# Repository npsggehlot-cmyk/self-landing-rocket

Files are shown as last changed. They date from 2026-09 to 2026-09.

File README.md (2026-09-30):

# Self-Landing TVC Rocket

This is my build log and source repository for a 3-inch model rocket that steers itself with a thrust-vectored motor and is designed to land on its own legs. Everything is here: the custom flight computer (RocketFC), the 3D-printed avionics bay, the servo-driven parachute ejector, the flight software, and the simulators I use to test ideas before flying them.

**Current status:** Flight computer v2.1 is ordered from JLCPCB, fully assembled. The firmware is written and has been tested in simulation. The avionics bay and chute ejector are designed and ready to print. Next up is bench testing once the boards arrive, followed by a first flight using the parachute.

| Flight computer (top) | Avionics bay | 3D flight simulator |
|---|---|---|
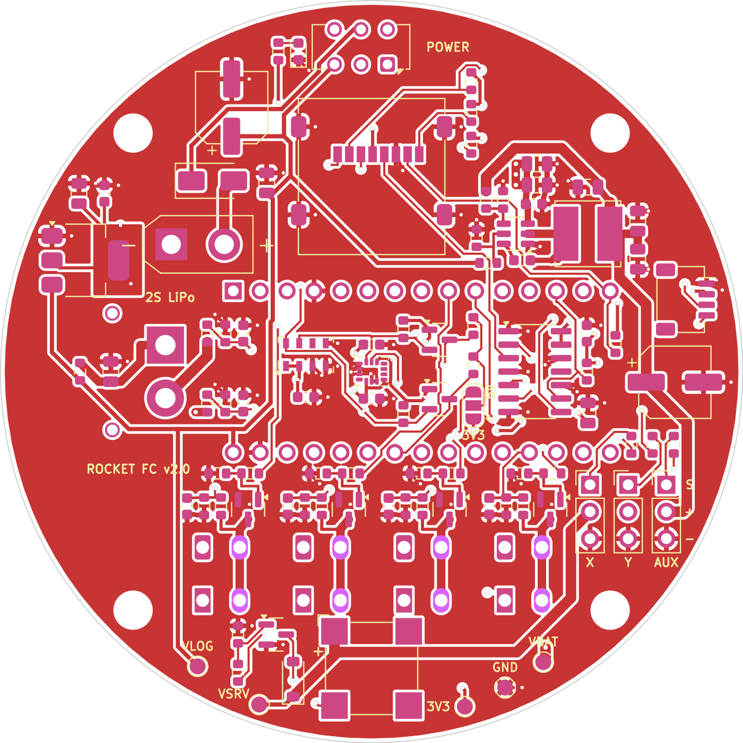
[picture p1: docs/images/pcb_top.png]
PCB top
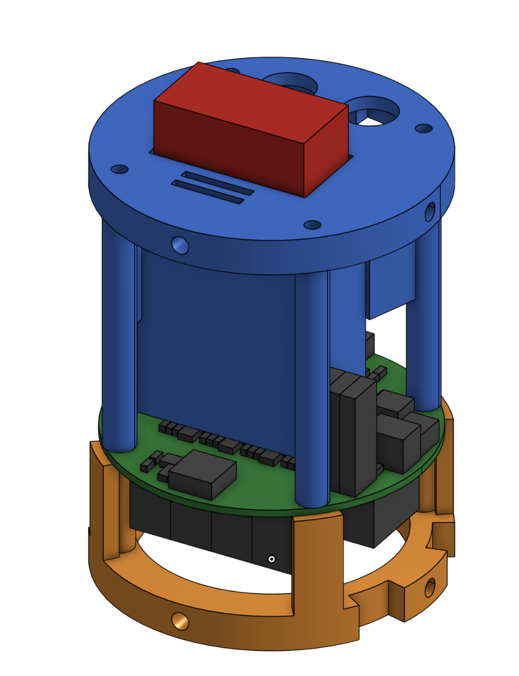
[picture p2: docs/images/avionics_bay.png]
Avionics bay
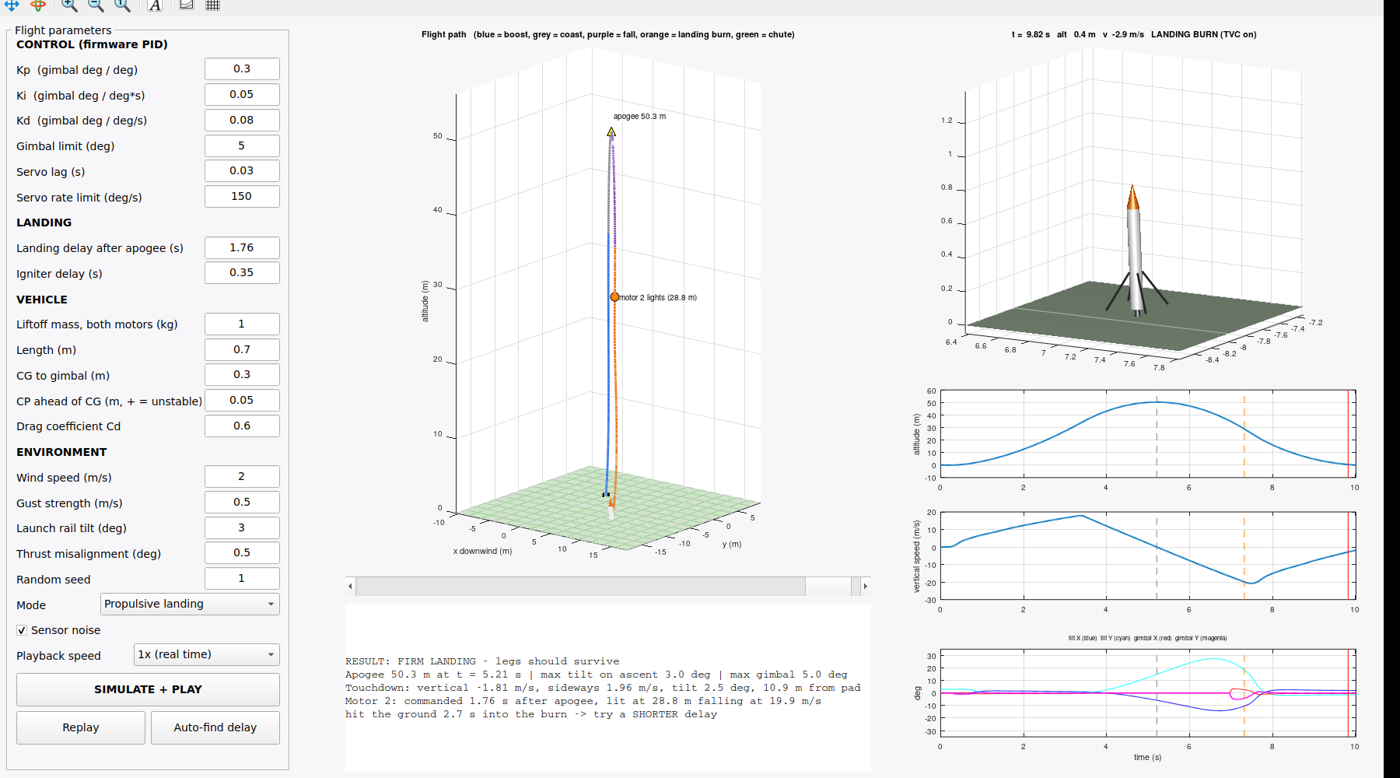
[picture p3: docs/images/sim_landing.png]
Simulator
|  |  |  |

---

## Mission profile

```mermaid
flowchart LR
    A[On the pad<br/>self-test beeps] -->|F15 #1 lit by<br/>launch controller| B[Boost<br/>TVC holds vertical]
    B -->|burnout at ~3.5 s| C[Coast]
    C -->|apogee| D{Flight mode}
    D -->|chute test| E[Servo releases the<br/>spring ejector and chute]
    D -->|landing| F[Free fall]
    F -->|timed so the burn<br/>ends at the ground| G[F15 #2 landing burn<br/>TVC on, legs released]
    E --> H[Legs released below 20 m]
    G --> I[Touchdown<br/>log closed, locator beeps]
    H --> I
```

## What's in this repo

| Folder | Contents | Start here |
|---|---|---|
| [`hardware/flight-computer`](hardware/flight-computer) | RocketFC v2.1, a 70 mm round 4-layer PCB designed in KiCad | `rocket_fc.kicad_pro`, plus Gerbers, BOM and CPL in `fabrication/` |
| [`hardware/avionics-bay`](hardware/avionics-bay) | Printed sled for the Apogee 3" tube, held in place by 8 radial M3 screws | STL and STEP files, tube drill template |
| [`hardware/chute-ejector`](hardware/chute-ejector) | Spring-loaded piston released by a servo-driven latch | Print-ready STLs |
| [`firmware/RocketFC`](firmware/RocketFC) | Arduino Nano flight software: TVC control, flight events, SD logging | `RocketFC.ino` |
| [`simulation/matlab`](simulation/matlab) | Interactive 3D flight simulator for tuning the PID gains and landing delay | `rocketSim3D.m` |
| [`simulation/firmware-sim`](simulation/firmware-sim) | Runs the actual flight firmware on a PC against simulated sensors | `sim.cpp` |
| [`LOG.md`](LOG.md) | Engineering log with a dated entry for each work session | |

## Flight computer overview

```
2S LiPo (XT30) ──┬── diode ── POWER switch ── Nano VIN + 3.3 V (sensors, SD card)
                 ├── 5 V 3 A buck, enabled by the switch ── 3 servos + buzzer
                 └── ARM plug (XT30) ── 4 low-side pyro channels (WAGO lever terminals)
```

| Function | Nano pin | Notes |
|---|---|---|
| Pyro P1 ascent, P2 landing, P3 legs, P4 spare | D2, D4, D6, D8 | AO3400A MOSFETs with 100k gate pull-downs; only live when the ARM plug is in |
| Continuity P1 to P4 | A0 to A3 | About 2.1 V when armed with an igniter connected, about 1.2 V when disarmed, 0 V when open |
| Servo X, servo Y (TVC), AUX (chute) | D3, D5, D7 | Powered from a separate 5 V buck converter |
| Battery and arm sense | A6, A7 | Battery voltage = A6 reading × 4.03 |
| IMU LSM6DSO32 (±32 g) and barometer MS5607 | I²C at 0x6A and 0x77 | Level-shifted to the 5 V Nano |
| microSD card (hinged lid) | SPI, D10 to D13 | Buffered through a 74LVC125 |
| Buzzer | D9 | Magnetic transducer, so it needs a tone rather than a steady signal |

Before ordering, the design passed a full design rule check with no errors, a pad-by-pad comparison between the schematic and the PCB (282 of 282 connections matched), an electrical rules check with no errors, and all 34 BOM lines were matched to parts in stock at JLCPCB.

## Key numbers

| | |
|---|---|
| Body tube | Apogee 3" (74.47 mm inner diameter); the bay and sled are 74.0 mm |
| Motors | 2 × Estes F15 (49.6 N·s total impulse, 25.3 N peak, 3.45 s burn) |
| Battery | 2S LiPo, 1000 mAh, 70 × 35 × 18 mm, XT30 connector |
| Simulated apogee at 1.0 kg | About 50 m |
| Best simulated landing delay | 1.76 s after apogee, with a window of roughly ±0.01 s |

## Links

- Onshape model of the avionics bay: [RocketFC Avionics Bay (3in Apogee tube)](https://cad.onshape.com/documents/a77bffe2781b56247ce74af7/w/bac2e3535b987d098c97ed26/e/773c68a36321aff5911a4cc4)

## Roadmap

- [x] Design, verify and order the flight computer PCB
- [x] Design the avionics bay and chute ejector
- [x] Write the firmware, compile it for the ATmega328P and test it in simulation
- [x] Build the 3D flight simulator in MATLAB
- [ ] Bench test the boards when they arrive: sensors, servos, and a pyro test with a small bulb
- [ ] Print the bay and ejector and test fit them in the tube
- [ ] Static test to measure the F15 igniter delay (`fire2` command)
- [ ] Flight 1: parachute mode with TVC on the way up
- [ ] Tune the PID gains using the flight logs
- [ ] Flight 2 and beyond: propulsive landing attempts

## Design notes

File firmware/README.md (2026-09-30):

# Firmware

`RocketFC/RocketFC.ino` builds in the Arduino IDE with the board set to "Arduino Nano" (ATmega328P). It only uses the built-in Wire, SPI, SD and Servo libraries.

Set `FLIGHT_MODE` near the top of the file, and fly the chute test first. For bench testing, open the Serial Monitor at 115200 baud with the line ending set to "Newline". The available commands are:

| Command | What it does |
|---|---|
| `s` | Prints status: sensors, battery, arm plug, continuity |
| `sweep` | Moves each TVC servo through its full range |
| `tvc` | Live TVC test, where the servos respond as you tilt the rocket |
| `open` / `lock` | Opens or locks the chute latch |
| `beep` | Tests the buzzer |
| `fire1` to `fire4` | Fires a pyro channel (only works with the ARM plug in) |

Each flight is logged to a new `FLTnn.CSV` file on the SD card.

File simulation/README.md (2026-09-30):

# Simulation

**`matlab/rocketSim3D.m`** runs in MATLAB, MATLAB Online or GNU Octave. Type `rocketSim3D`, adjust the PID gains, landing delay, mass or wind, and press SIMULATE + PLAY. The Auto-find button searches for the landing delay that gives the softest touchdown.

**`firmware-sim/`** compiles the real `RocketFC.ino` on a regular computer and runs it against simulated sensors:

```
g++ -O1 -w -Istub -o sim sim.cpp -lm
./sim 0    # 0 = chute flight, 1 = bump on the pad, 2 = landing
```

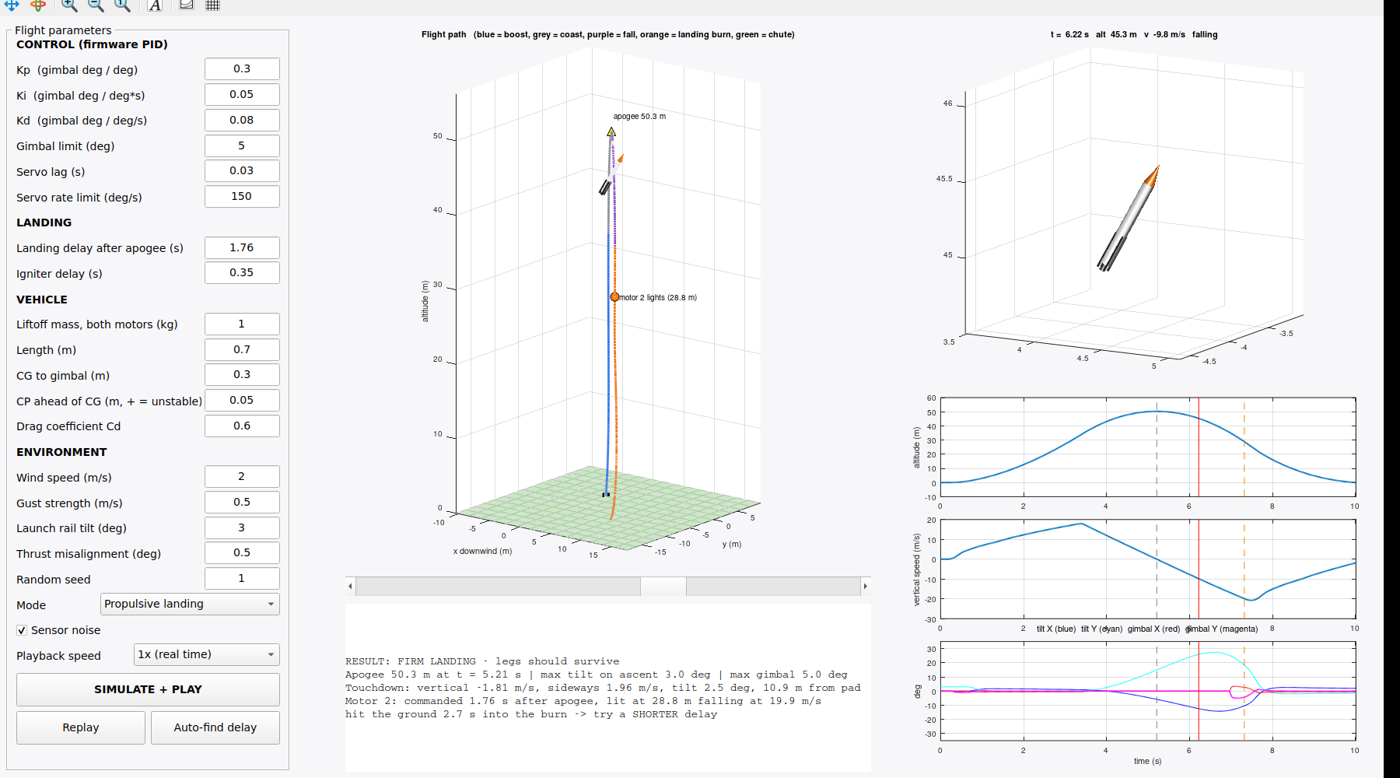
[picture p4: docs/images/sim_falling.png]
sim


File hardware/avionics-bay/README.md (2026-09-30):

# Avionics bay (Apogee 3" tube)

Print `AvBay_Aft.stl` and `AvBay_Forward.stl` in PETG. Joined by 4 × M3 × ~100 mm rods through the PCB holes (nut traps in the aft face).
8 × M3 heat-set inserts (4.0 mm hole) in radial bosses; drill the tube with `AvBay_Tube_Drill_Template.pdf` (print at 100 %).
Onshape: https://cad.onshape.com/documents/a77bffe2781b56247ce74af7/w/bac2e3535b987d098c97ed26/e/773c68a36321aff5911a4cc4
bay

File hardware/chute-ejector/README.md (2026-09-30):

# Servo parachute ejector

A compression spring (22 mm OD, 1.4–1.5 mm wire, 100 mm free, compressed to 35 mm) pushes a piston that throws out the chute.
A T-headed stem through the bulkhead is held by a latch cup on an MG90S servo horn; turning 90° lines up the slots and releases it.
The spring load goes into the cup and bulkhead, not the servo.

Print (PETG, no supports): `Print_Chute_Bulkhead.stl`, `Print_Chute_LatchCup.stl`, `Print_Chute_Stem.stl`, `Print_Chute_Piston.stl`.
Hardware: MG90S, 4 × M3 × 8 + heat-set inserts, M2 servo screws, Kevlar shock cord.
Arming: `open` → push the piston down until the T-head drops into the cup → `lock`.
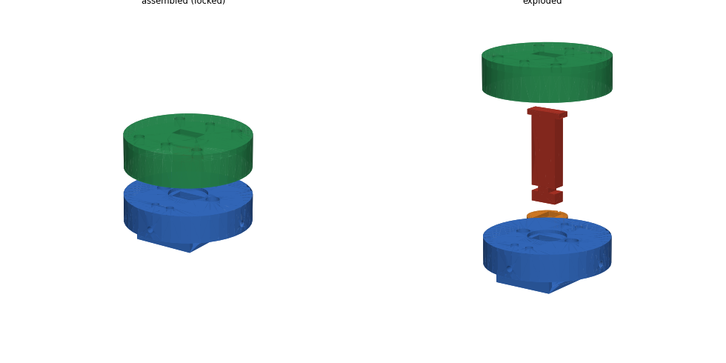
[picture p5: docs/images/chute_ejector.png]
ejector


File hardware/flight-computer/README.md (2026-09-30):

# RocketFC v2.1 flight computer PCB

Open `rocket_fc.kicad_pro` in KiCad 7 or newer.

- `fabrication/` holds exactly what was sent to JLCPCB: the Gerbers plus the full-assembly BOM and CPL files.
- `scripts/` has the Python scripts used to generate the schematic and board. `design.py` is the single source of truth for every part and net.
- `lib/` contains a local footprint for the WAGO 2601 lever terminals.

JLCPCB settings used: 4 layers, 1.6 mm, ENIG, Standard PCBA, assembly on both sides, parts placement confirmation, and depaneling.

When bringing up a new board, check the test pads first. VLOG should read about 7.9 V, VSRV 5.0 V and 3V3 3.3 V.

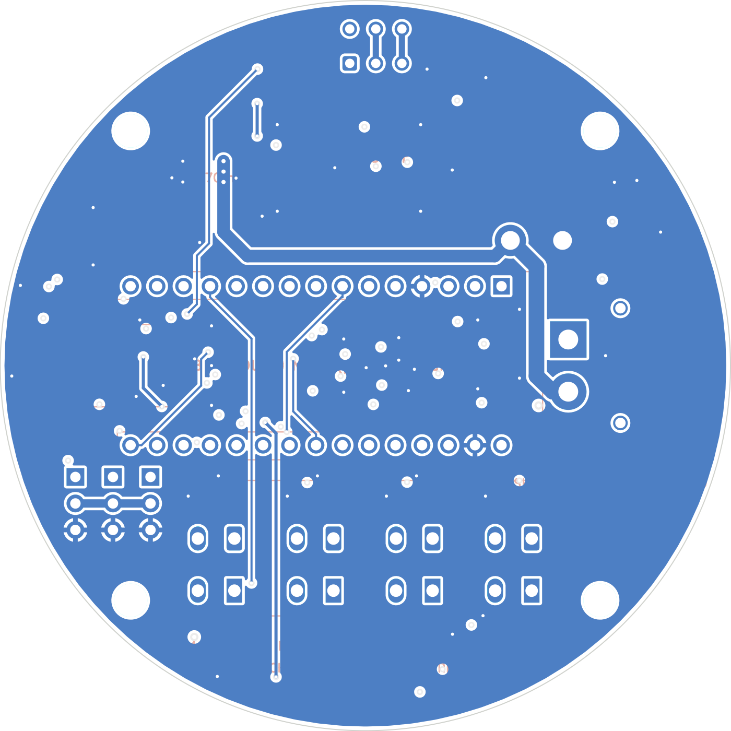
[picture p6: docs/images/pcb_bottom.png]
bottom
top

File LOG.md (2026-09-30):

# Engineering Log

Newest entries go at the top. Each entry covers one work session: what changed, why it changed, and what comes next. There's a blank template at the bottom of this file to copy for new entries.

---

## 2026-09-29: Firmware, 3D simulator and final PCB fixes

**Flight computer v2.1**
- A final review turned up one real problem. The I²C pull-up jumper (JP1) was shipping open, which would have required a solder bridge by hand. I tied it to the Nano's 5 V rail in copper, so the board now needs no hand soldering at all.
- Re-verified the Nano pin map against the KiCad library, compared the schematic to the PCB pad by pad (282 of 282 matched), and confirmed the design rule check and electrical rules check were both clean. Also double-checked the battery connector polarity (the chamfered side of an XT30 is negative) and the power switch wiring.
- Switched the JLCPCB order to full assembly: all surface-mount parts, the through-hole connectors and the Nano sockets, on both sides, with the edge rails removed. The Nano plugs into its sockets with the USB port facing the "< USB" arrow.

**Firmware (`firmware/RocketFC/RocketFC.ino`)**
- The flight states are PAD, BOOST, COAST, then either CHUTE or WAIT_IGNITE, then LAND_BURN and finally LANDED.
- TVC uses a gyro-integrated quaternion for attitude and a PID loop on tilt, with starting gains of Kp 0.30, Ki 0.05 and Kd 0.08 (degrees of gimbal per degree of tilt).
- Liftoff is detected at 1.5 g sustained for 50 ms, and the rocket must then climb 3 m within 2.5 s. If it doesn't, the computer goes back to the pad state, so bumping the rocket on the pad can't trigger the chute.
- An F15 can't be throttled, so the landing motor fires when a burn started at that moment would end right at the ground. If the apogee makes a soft landing impossible, the computer deploys the parachute instead.
- It fits on the Nano: 30,370 of 30,720 bytes of flash and 1,427 of 2,048 bytes of RAM.
- I ran the actual firmware against simulated sensors. The chute flight worked, a bump on the pad was correctly ignored, and the landing sequence worked.

**Chute ejector**
- A spring-loaded piston (22 mm OD spring, 100 mm free length) is held by a T-shaped stem that sits in a latch cup on an MG90S servo. Turning the servo 90° lines up the slots and releases it.

**3D simulator (`simulation/matlab/rocketSim3D.m`)**
- Lets me adjust the PID gains, the landing delay after apogee, the rocket's mass, CP/CG position, wind and more. An auto-find button searches for the softest landing.
- The best delay came out to about 1.76 s at 1.0 kg, and the usable window is only about ±0.01 s wide. The rocket also tilts 16 to 27° while coasting and falling, since there are no fins and the TVC is off, but the landing burn straightens it out in about 0.4 s.

**Next:** The boards should ship around October 8. Then comes bench testing.

---

## 2026-09-28: Flight computer v1 to v2, and the avionics bay

- Designed RocketFC in KiCad around an Arduino Nano and a 2S LiPo, with 4 pyro channels, 3 servo outputs, an IMU, a barometer and a microSD card.
- For v2, I shrank it to a 70 mm round board so it fits inside the Apogee 3" tube with room for the wall thickness, and moved the mounting holes to a standard 45 × 45 mm M3 pattern.
- Designed the avionics bay in Onshape and CadQuery. An aft ring and a forward bulkhead are joined by 4 M3 tie rods that pass through the PCB's mounting holes. 8 radial M3 heat-set inserts take screws through the tube wall, and there's a pocket for a 2S 1000 mAh battery.
- Fixed the geometry problems that caused Onshape import errors (curves, seam placement and thin walls).

---

## Template

```
## YYYY-MM-DD: Title

**What I did**
-

**What I learned or what went wrong**
-

**Data and photos** (images go in docs/images/, flight logs in data/)
-

**Next**
-
```

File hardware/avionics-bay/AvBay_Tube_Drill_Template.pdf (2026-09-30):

FORWARD (nose) end of the bay

RocketFC v2 avionics bay - tube drilling template (Apogee 3.0" / 74 mm body tube, OD 76.2 mm)

Print at 100 % (no "fit to page"), check the 50 mm bar, cut on the outline, wrap it around the tube printed side out, FORWARD edge toward the nose, left and right edges meeting. 8 small circles = 3.2 mm drill for M3 x 8 button-head screws into the heat-set inserts. Hatched boxes = openings to cut (USB, ARM plug, power switch).
Slide the bay in from the forward end with the power switch at 12 o'clock and line its screw holes up with the tube before drilling full size.

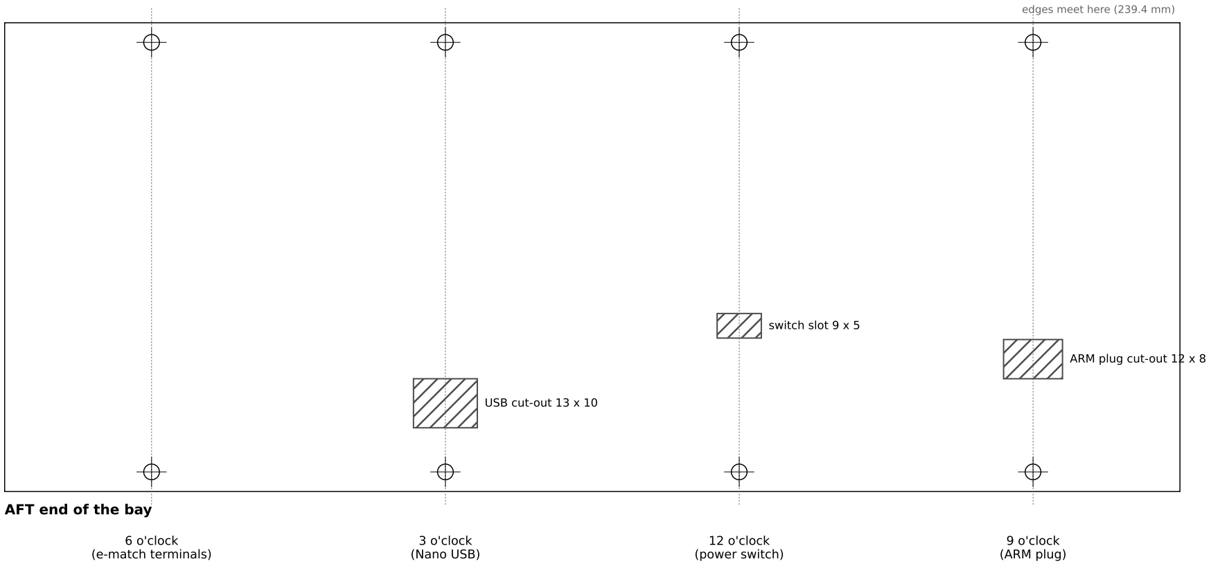
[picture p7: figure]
edges meet here (239.4 mm); 6 o'clock (e-match terminals); 3 o'clock (Nano USB); 12 o'clock (power switch); 9 o'clock (ARM plug); USB cut-out 13 x 10; ARM plug cut-out 12 x 8; switch slot 9 x 5; AFT end of the bay

50 mm check bar

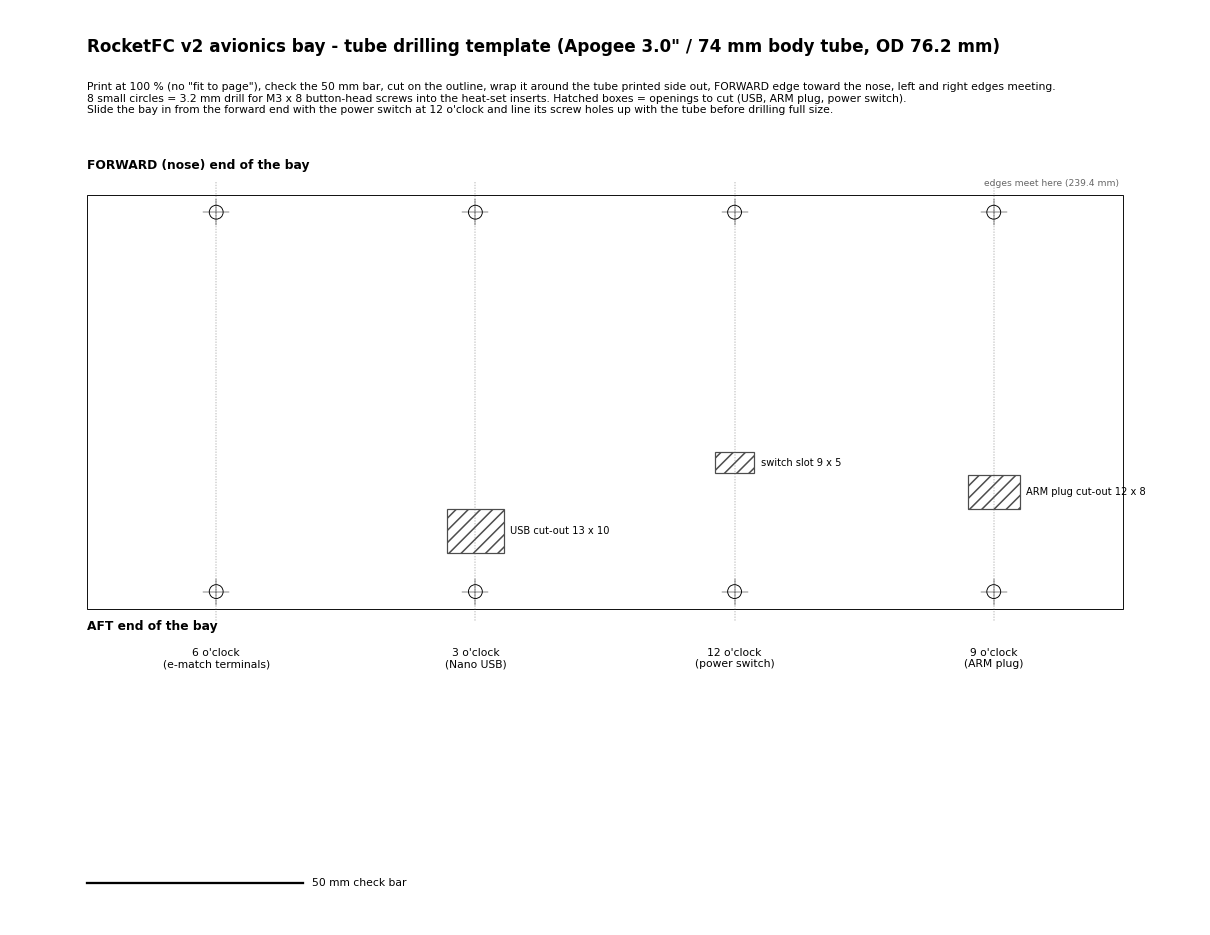
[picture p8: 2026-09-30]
docs/images/drill_template.png

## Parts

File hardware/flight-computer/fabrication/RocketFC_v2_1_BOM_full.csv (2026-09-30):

Comment | Designator | Footprint | LCSC Part #
CMT-8504 5V 100dB | BZ1 | MagneticBuzzer_CUI_CMT-8504-100-SMT | C22359707
220uF 16V | C1,C13 | CP_Elec_6.3x7.7 | C178534
10uF 25V | C2,C6,C7,C15,C24 | C_0805_2012Metric | C15850
10nF | C3,C14,C16,C17,C18,C19 | C_0603_1608Metric | C57112
22uF 25V | C4,C10,C11,C12 | C_0805_2012Metric | C45783
100nF | C5,C8,C9,C20,C21,C22,C23 | C_0603_1608Metric | C14663
SS34 | D1 | D_SMA | C8678
RED | D2 | LED_0603_1608Metric | C2286
1N4148W | D3 | D_SOD-123 | C81598
BATTERY 2S (XT30 male, vertical) | J1 | AMASS_XT30UPB-M_1x02_P5.0mm_Vertical | C428721
2.54mm 1x3 male header | J2,J3,J4 | PinHeader_1x03_P2.54mm_Vertical | C49257
ARM PLUG (XT30 female) | J5 | AMASS_XT30PW-F_1x02_P2.50mm_Horizontal | C2913282
WAGO 2601-3102 (lever) | J6,J7,J8,J9 | TerminalBlock_WAGO_2601-3102_1x02_P3.50mm_Vertical | C20252913
microSD (hinged lid) | J10 | microSD_HC_Molex_47219-2001 | C164170
QWIIC (GPS / rangefinder) | J11 | JST_SH_SM04B-SRSS-TB_1x04-1MP_P1.00mm_Horizontal | C160404
2.2uH | L1 | L_Bourns_SRN6045TA | C1332316
AO3400A | Q1,Q2,Q3,Q4,Q5 | SOT-23 | C20917
BSS138 | Q6,Q7 | SOT-23 | C40912
100k | R1,R4,R6,R7,R12,R15,R16,R19,R20,R23,R24,R27,R28,R31 | R_0603_1608Metric | C25803
33k | R2,R13,R17,R21,R25,R29 | R_0603_1608Metric | C4216
1k | R3 | R_0603_1608Metric | C21190
18k | R5 | R_0603_1608Metric | C25810
220 | R8,R9,R10 | R_0603_1608Metric | C22962
47k | R11 | R_0603_1608Metric | C25819
100 | R14,R18,R22,R26,R30 | R_0603_1608Metric | C22775
4.7k | R32,R33,R34,R35 | R_0603_1608Metric | C23162
10k | R36,R37,R38,R39,R40 | R_0603_1608Metric | C25804
POWER | SW1 | SW_CK_JS202011AQN_DPDT_Angled | C221662
AMS1117-3.3 | U1 | SOT-223-3_TabPin2 | C6186
TPS563200 | U2 | SOT-23-6 | C97253
LSM6DSO32 | U3 | LGA-14_3x2.5mm_P0.5mm_LayoutBorder3x4y | C1864162
MS5607-02BA03 | U4 | LGA-8_3x5mm_P1.25mm | C97627
74LVC125A | U5 | SOIC-14_3.9x8.7mm_P1.27mm | C7661
Nano socket 1x15 female 2.54mm | A1_S1,A1_S2 | PinSocket_1x15_P2.54mm_Vertical | C41417327

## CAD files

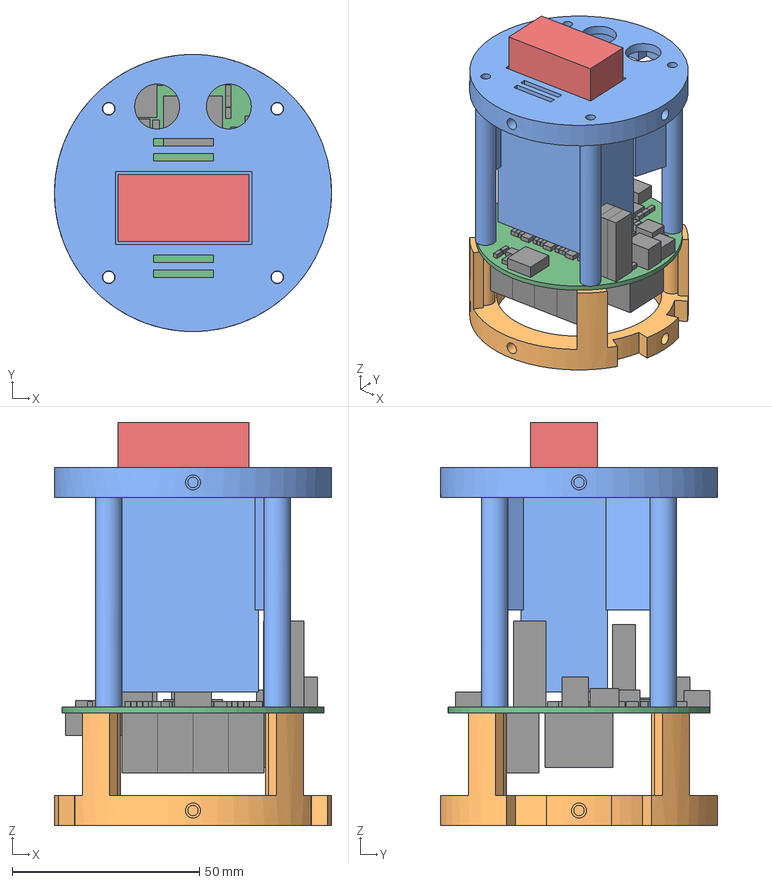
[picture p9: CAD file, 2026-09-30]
hardware/avionics-bay/AvBay_Assembly.step
74.0 x 74.0 x 107.6 mm
Sled_Aft
Sled_Forward
PCB_RocketFC_v2
PCB_component_envelopes
Battery_2S_1000mAh_70x35x18

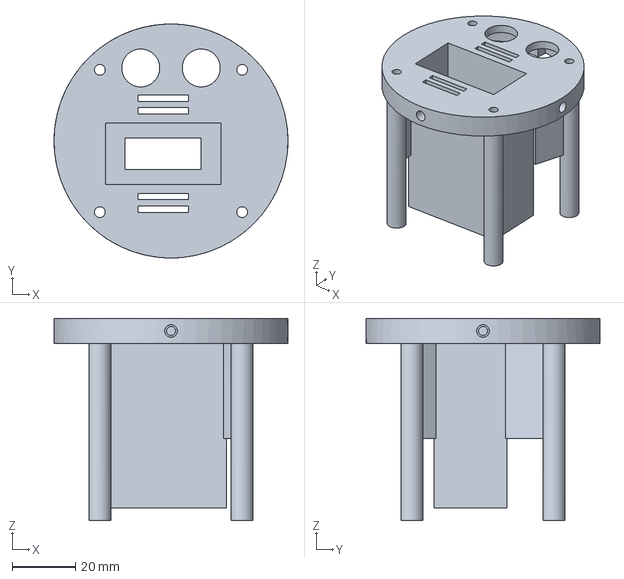
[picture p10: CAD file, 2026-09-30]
hardware/avionics-bay/AvBay_Forward.step
74.0 x 74.0 x 64.0 mm

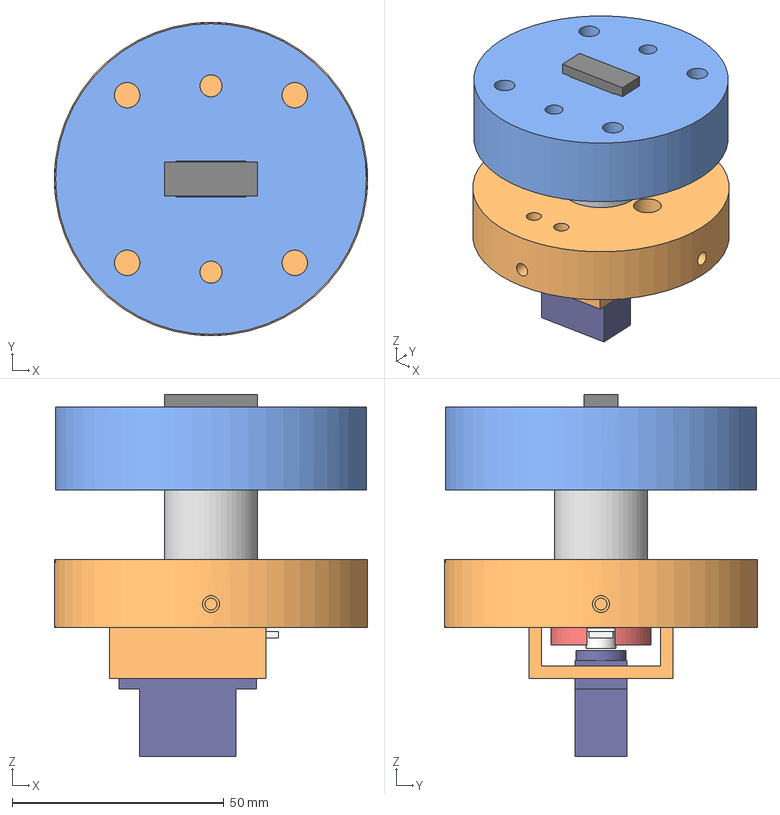
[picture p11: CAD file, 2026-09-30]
hardware/chute-ejector/RocketFC_Chute_Ejector.step
74.0 x 74.0 x 85.5 mm
Bulkhead_ServoFrame
Latch_Cup
Latch_Stem
Piston
REF_MG90S_servo
REF_servo_horn
REF_spring_20OD_x_100free

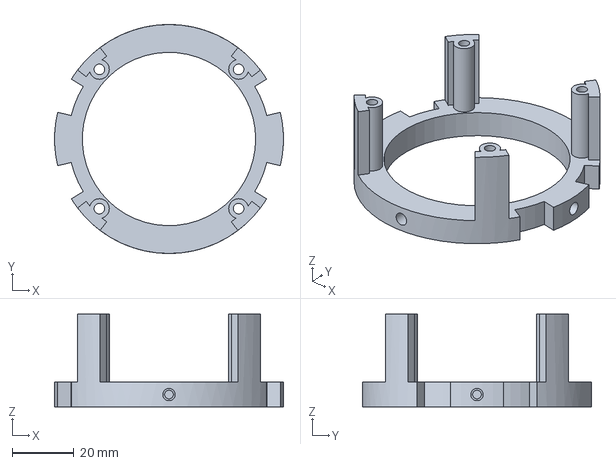
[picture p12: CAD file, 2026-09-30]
hardware/avionics-bay/AvBay_Aft.step
74.0 x 74.0 x 30.0 mm

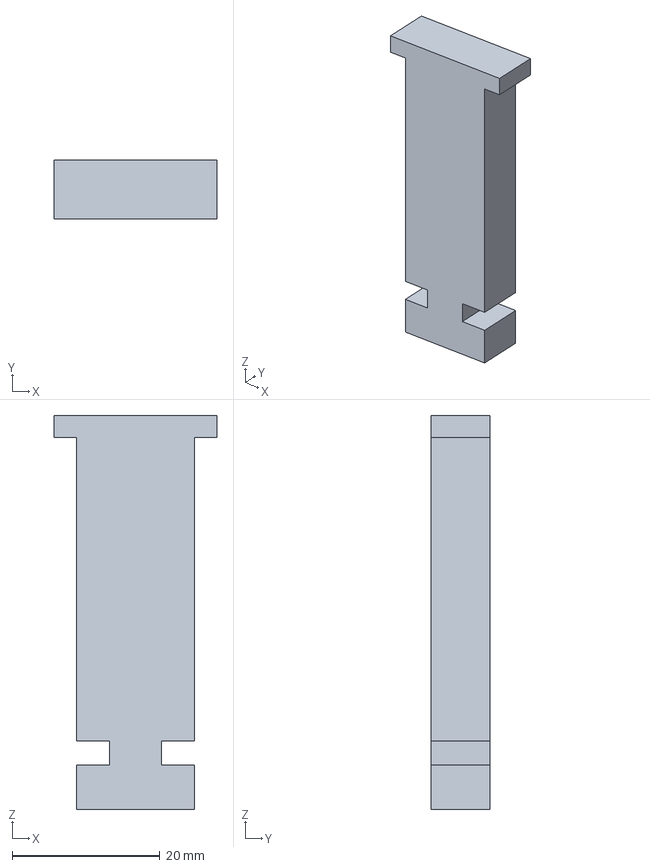
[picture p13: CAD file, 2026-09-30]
hardware/chute-ejector/ChuteEjector_stem.step
22.0 x 8.00 x 53.3 mm

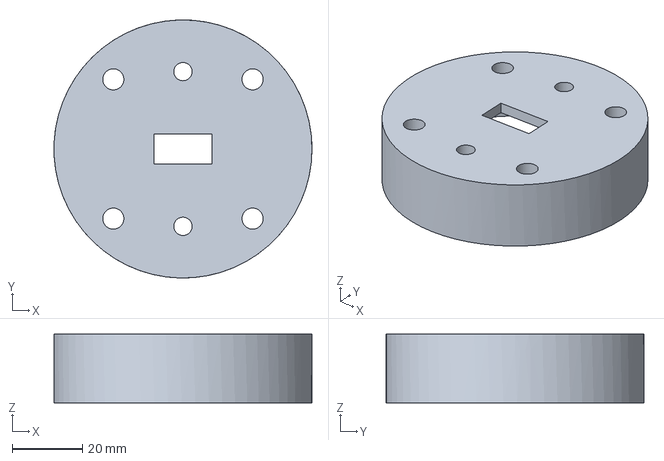
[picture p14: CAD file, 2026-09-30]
hardware/chute-ejector/ChuteEjector_piston.step
73.4 x 73.4 x 19.5 mm

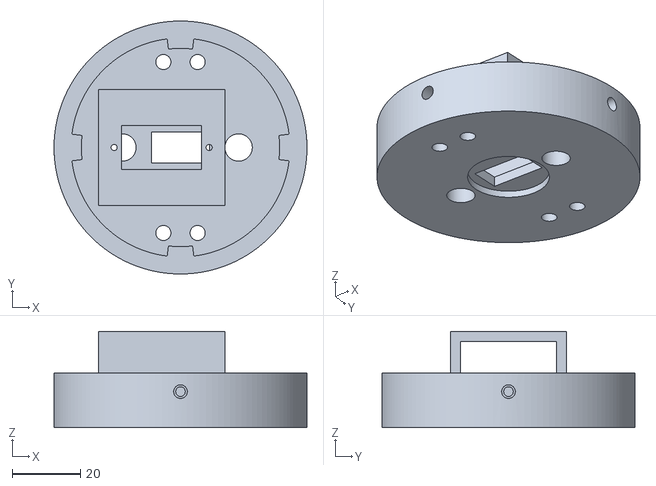
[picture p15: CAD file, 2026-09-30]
hardware/chute-ejector/Print_Chute_Bulkhead.stl
74.0 x 74.0 x 28.1

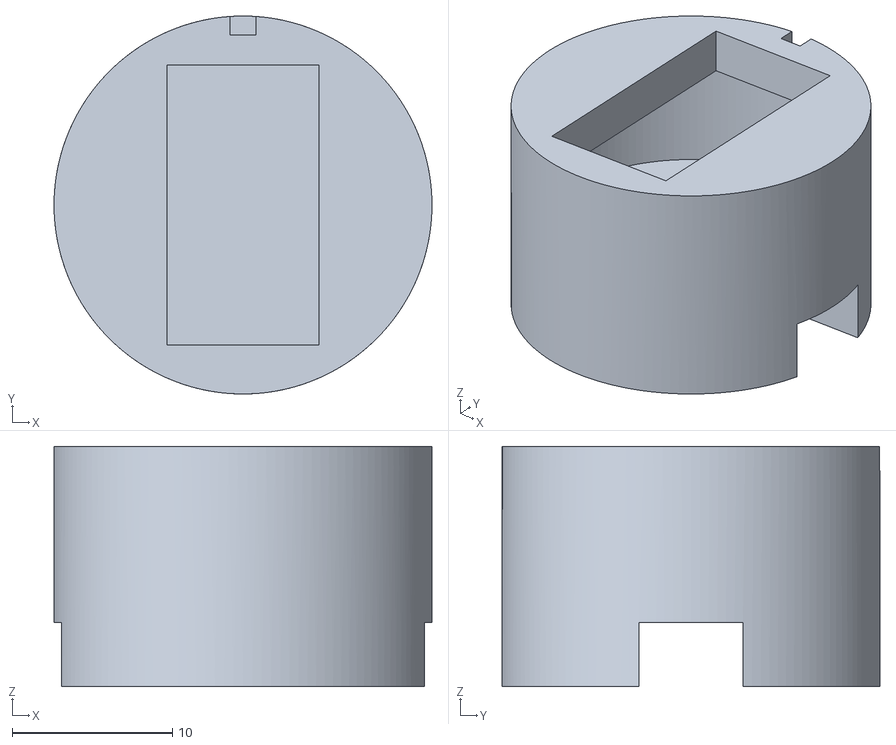
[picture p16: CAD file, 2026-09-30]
hardware/chute-ejector/Print_Chute_LatchCup.stl
23.6 x 23.6 x 15.0

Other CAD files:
hardware/chute-ejector/Print_Chute_Piston.stl
hardware/chute-ejector/ChuteEjector_bulkhead.step
hardware/chute-ejector/ChuteEjector_cup.step
hardware/chute-ejector/Print_Chute_Stem.stl
hardware/avionics-bay/AvBay_Aft.stl
hardware/avionics-bay/AvBay_Forward.stl

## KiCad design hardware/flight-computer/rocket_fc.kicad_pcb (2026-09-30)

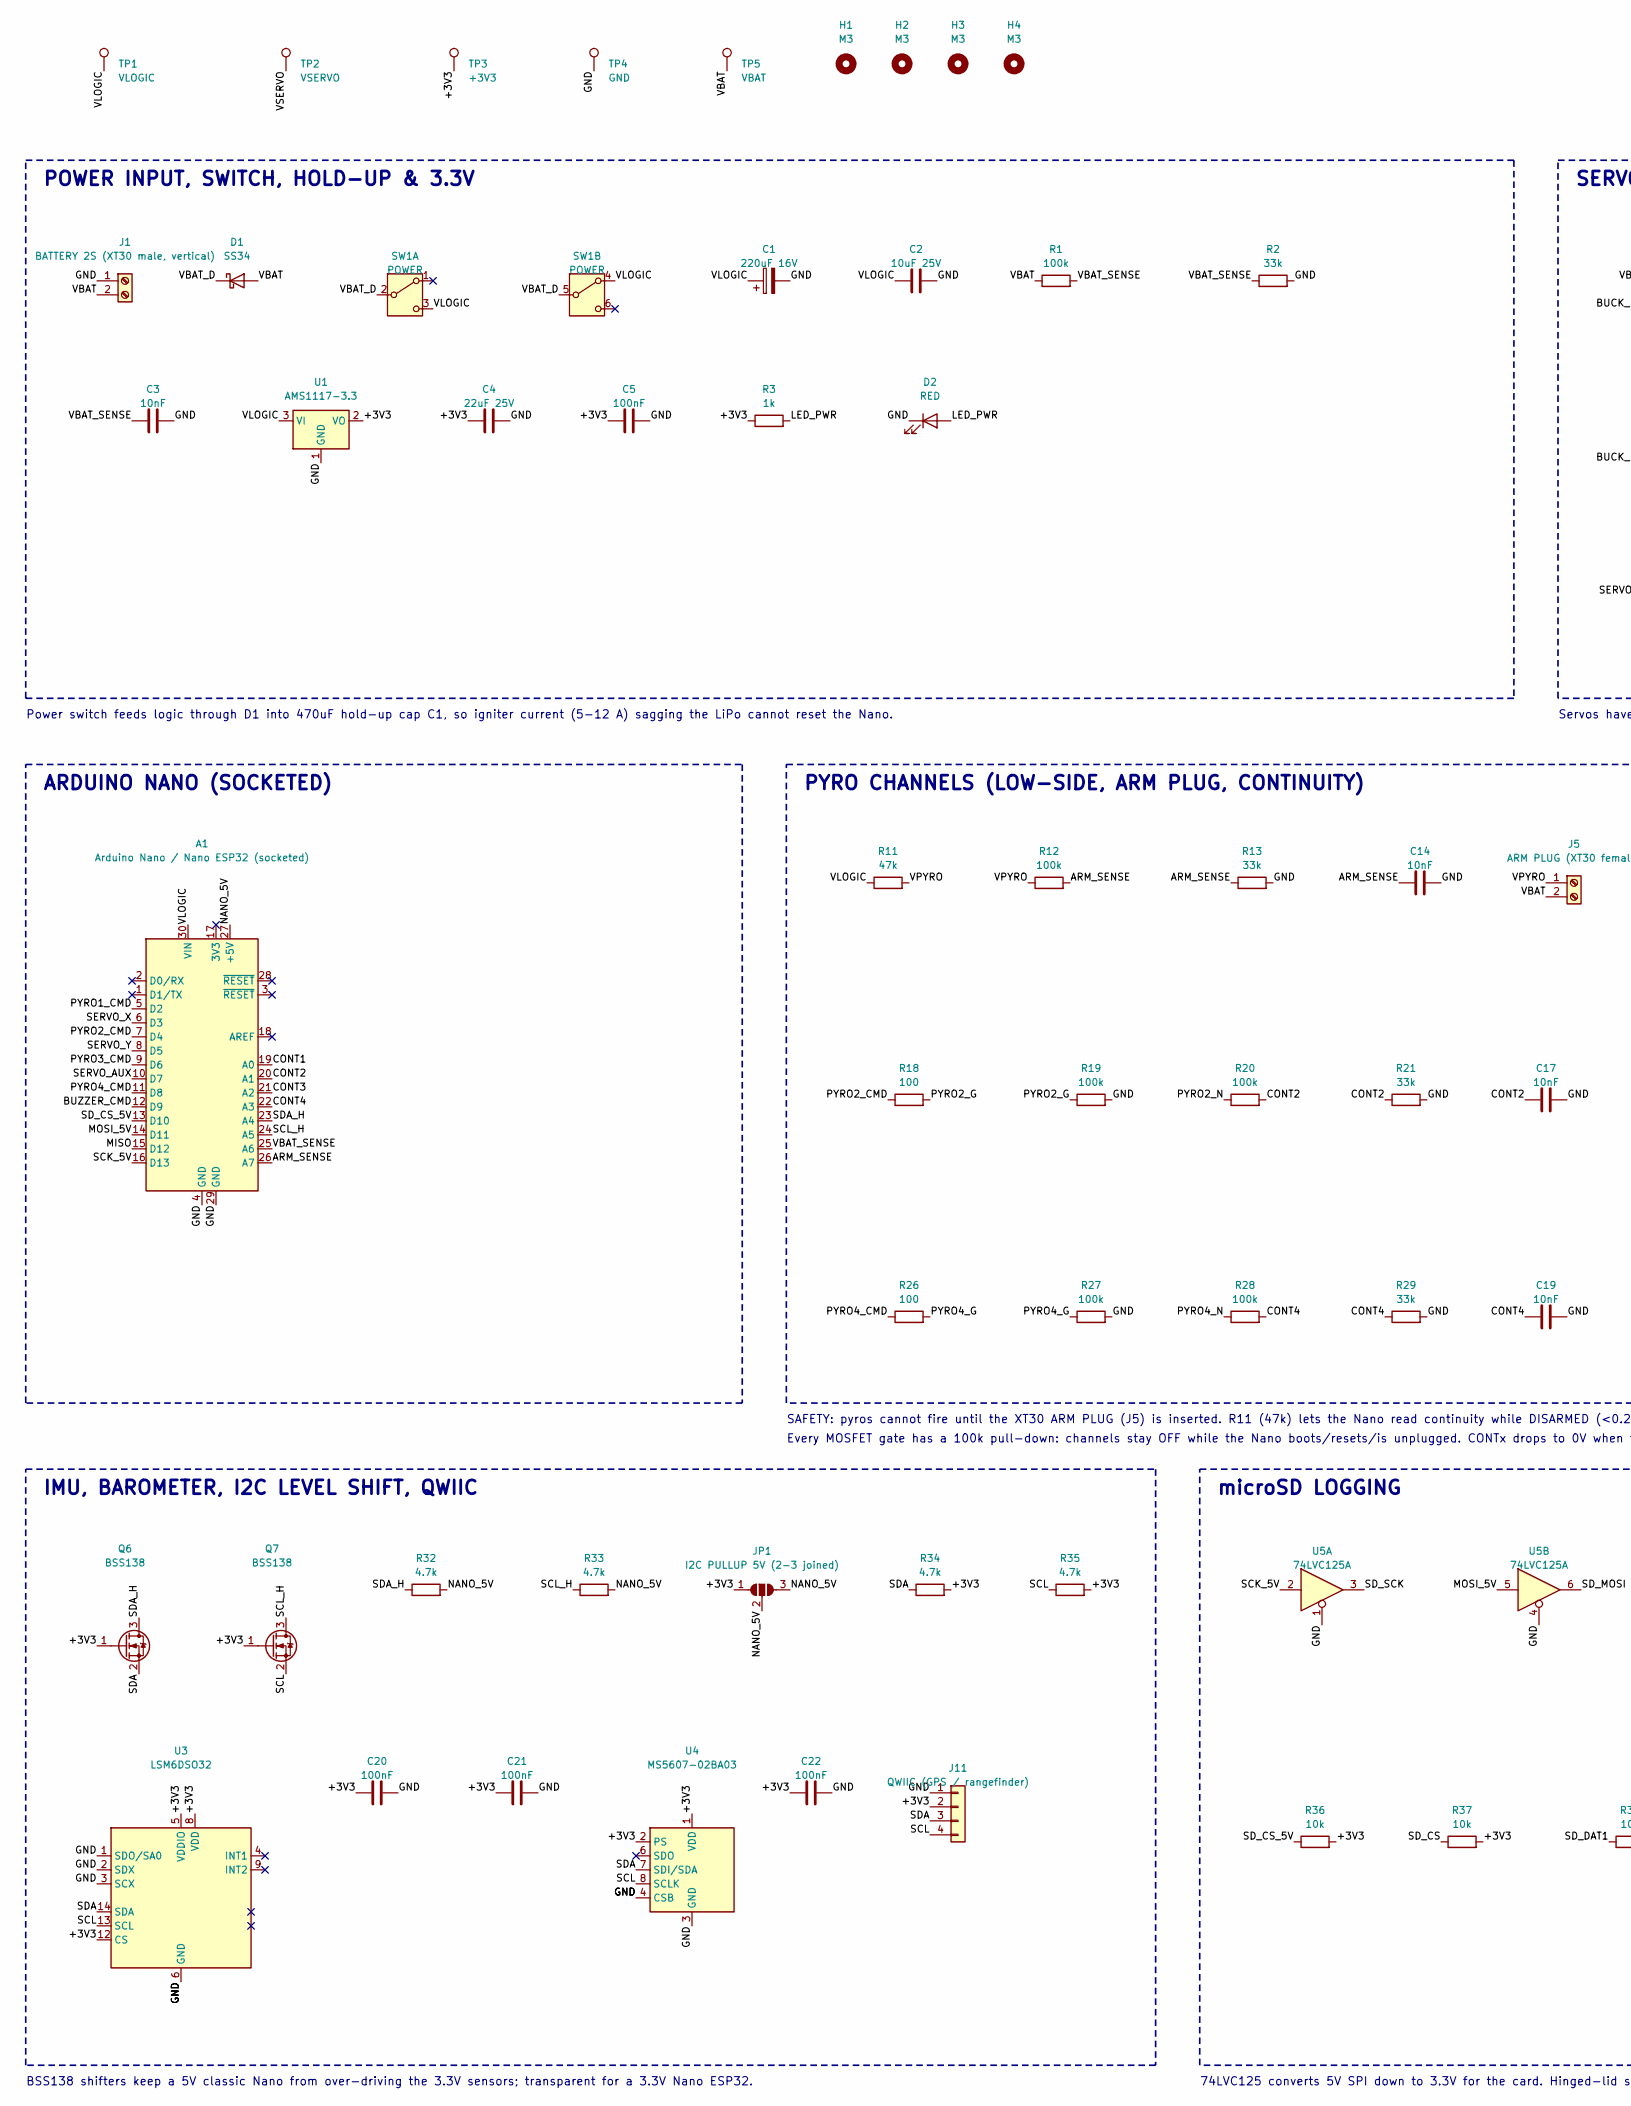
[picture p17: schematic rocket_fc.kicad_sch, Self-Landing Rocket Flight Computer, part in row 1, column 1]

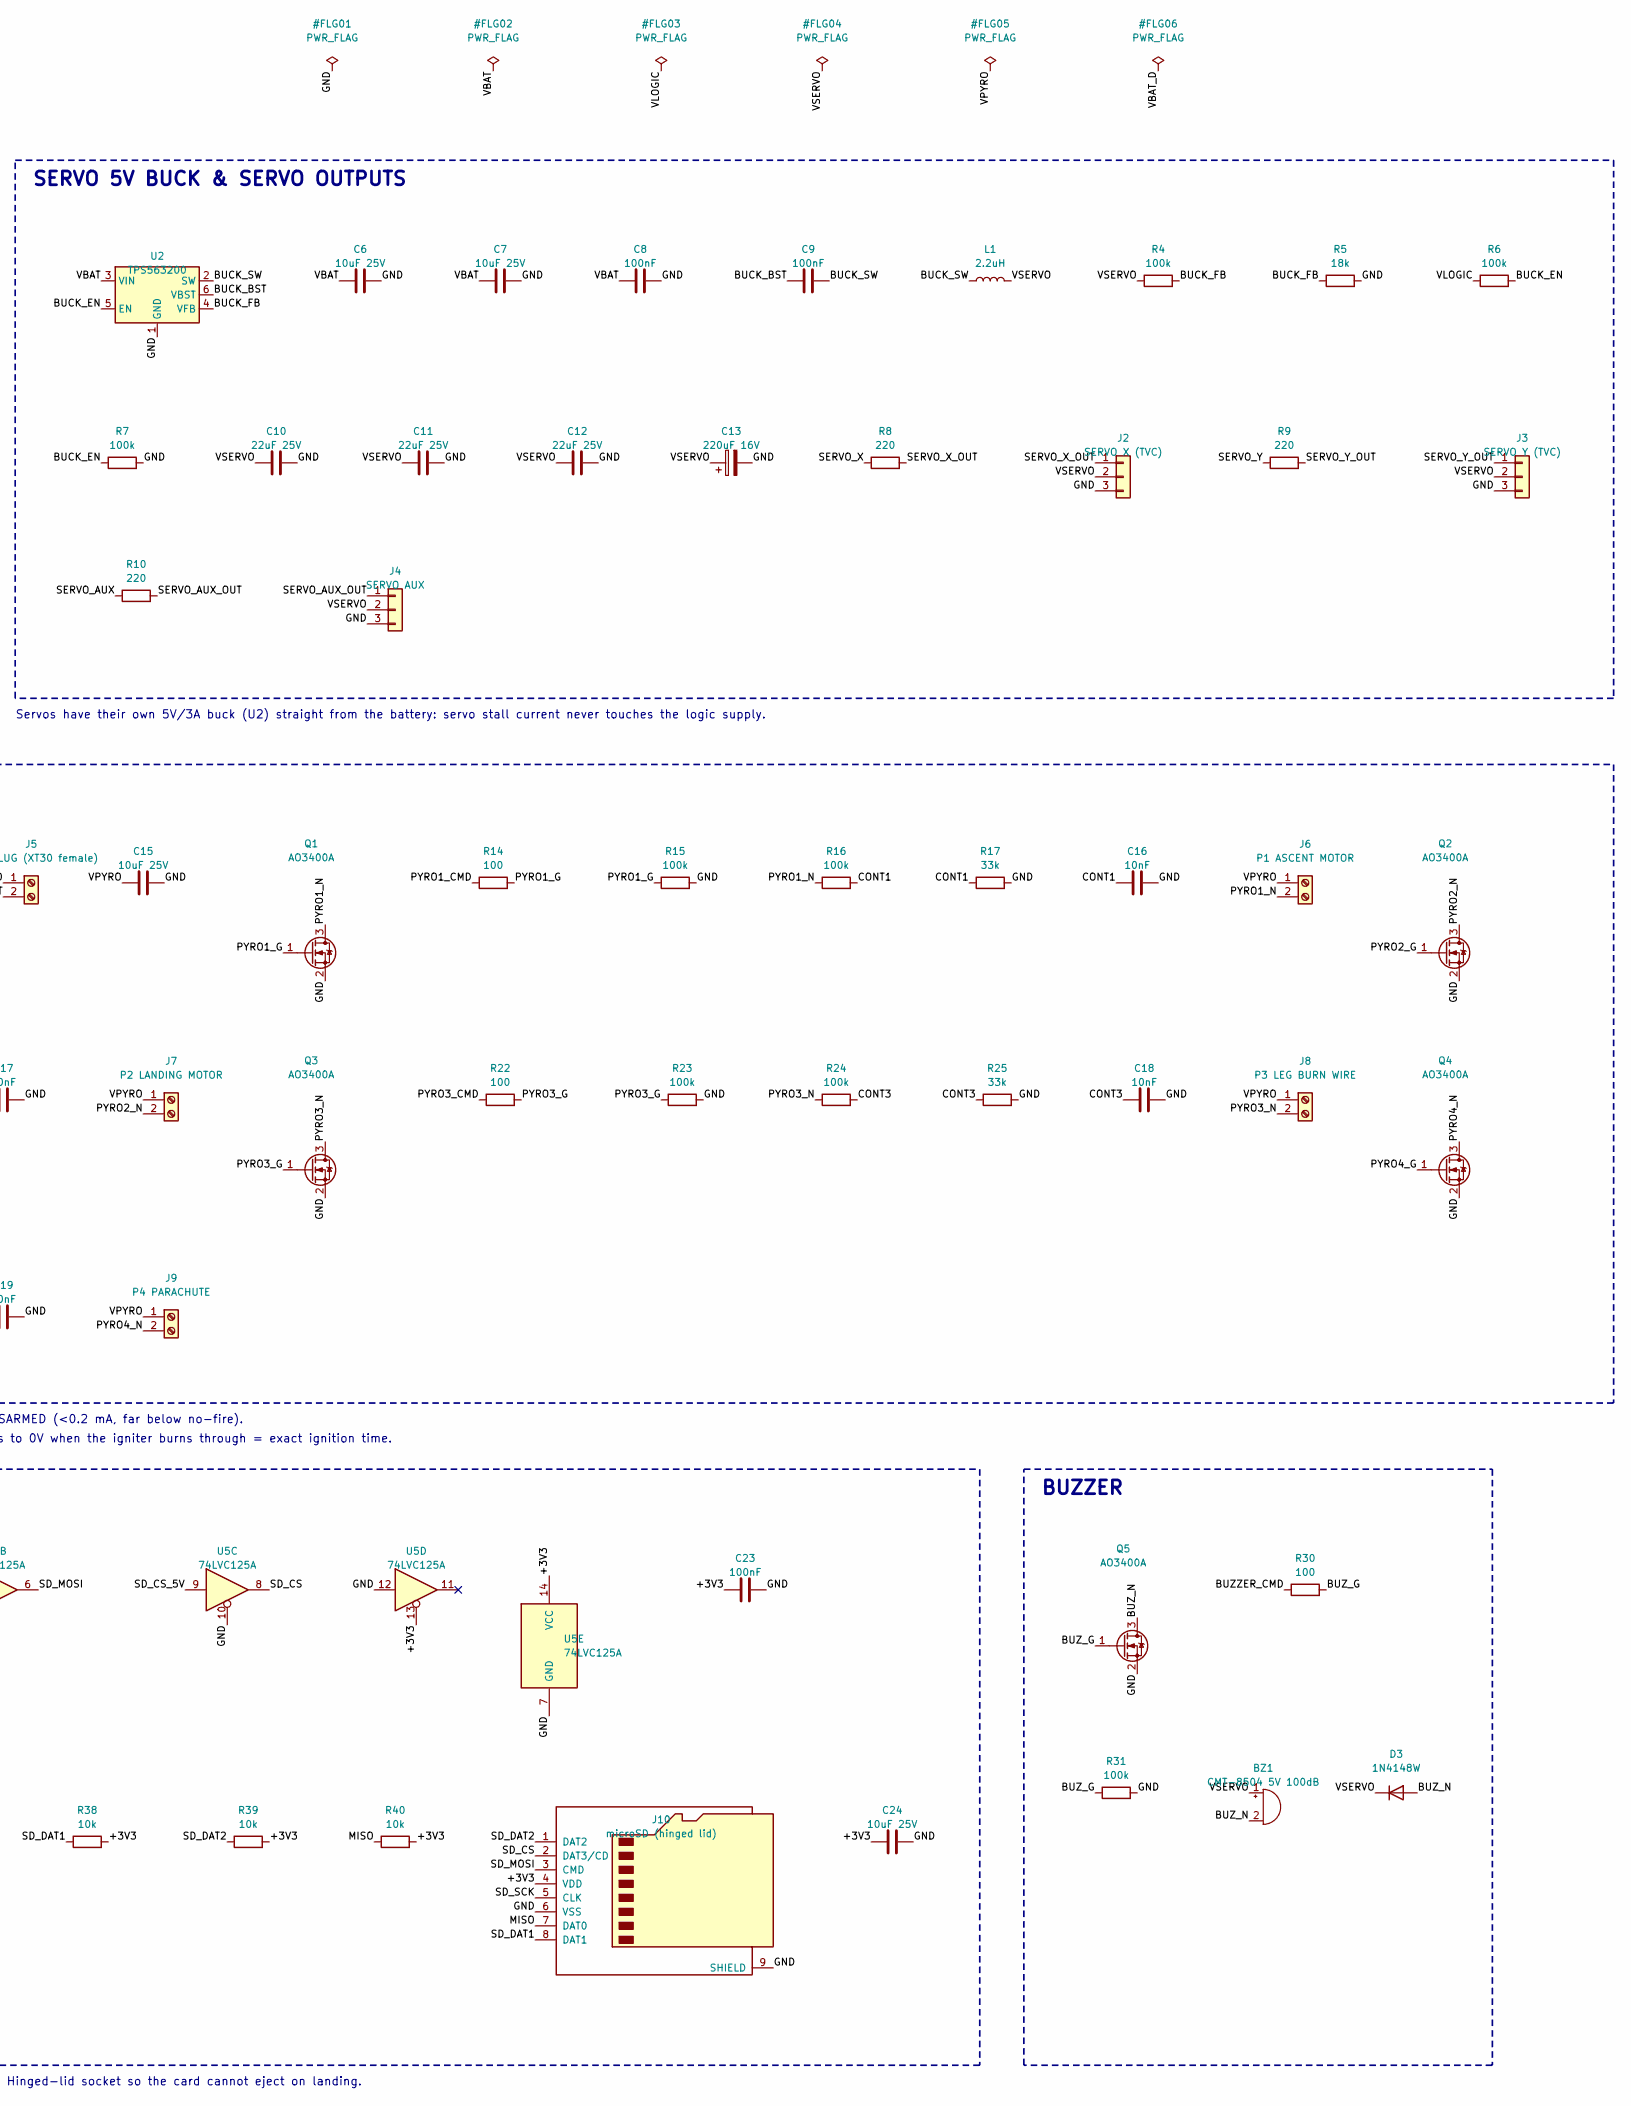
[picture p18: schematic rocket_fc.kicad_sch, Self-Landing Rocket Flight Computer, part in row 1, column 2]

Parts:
A1: Arduino Nano / Nano ESP32 (socketed); Arduino_Nano; MPN 2x 1x15 2.54mm female header (socket)
BZ1: CMT-8504 5V 100dB; MagneticBuzzer_CUI_CMT-8504-100-SMT; MPN Same Sky (CUI) CMT-8504-100-SMT-TR magn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; LCSC C22359707
C1: 220uF 16V; CP_Elec_6.3x7.7; MPN Panasonic EEE-FK1C221P 220uF 16V (brown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; LCSC C178534
C2, C6, C7, C15, C24: 10uF 25V; C_0805_2012Metric; LCSC C15850
C3, C14, C16, C17, C18, C19: 10nF; C_0603_1608Metric; LCSC C57112
C4, C10, C11, C12: 22uF 25V; C_0805_2012Metric; LCSC C45783
C5, C8, C9, C20, C21, C22, C23: 100nF; C_0603_1608Metric; LCSC C14663
C13: 220uF 16V; CP_Elec_6.3x7.7; MPN Panasonic EEE-FK1C221P 220uF 16V (servo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; LCSC C178534
D1: SS34; D_SMA; MPN SS34 (40V 3A Schottky); LCSC C8678
D2: RED; LED_0603_1608Metric; MPN KT-0603R red LED; LCSC C2286
D3: 1N4148W; D_SOD-123; MPN 1N4148W; LCSC C81598
H1, H2, H3, H4: M3; MountingHole_3.2mm_M3
J1: BATTERY 2S (XT30 male, vertical); AMASS_XT30UPB-M_1x02_P5.0mm_Vertical; MPN AMASS XT30UPB-M; LCSC C428721
J2: SERVO X (TVC); PinHeader_1x03_P2.54mm_Vertical; MPN 2.54mm 1x3 male header; LCSC C49257
J3: SERVO Y (TVC); PinHeader_1x03_P2.54mm_Vertical; MPN 2.54mm 1x3 male header; LCSC C49257
J4: SERVO AUX; PinHeader_1x03_P2.54mm_Vertical; MPN 2.54mm 1x3 male header; LCSC C49257
J5: ARM PLUG (XT30 female); AMASS_XT30PW-F_1x02_P2.50mm_Horizontal; MPN AMASS XT30PW-F; LCSC C2913282
J6: P1 ASCENT MOTOR; TerminalBlock_WAGO_2601-3102_1x02_P3.50mm_Vertical; MPN WAGO 2601-3102 (lever); LCSC C20252913
J7: P2 LANDING MOTOR; TerminalBlock_WAGO_2601-3102_1x02_P3.50mm_Vertical; MPN WAGO 2601-3102 (lever); LCSC C20252913
J8: P3 LEG BURN WIRE; TerminalBlock_WAGO_2601-3102_1x02_P3.50mm_Vertical; MPN WAGO 2601-3102 (lever); LCSC C20252913
J9: P4 PARACHUTE; TerminalBlock_WAGO_2601-3102_1x02_P3.50mm_Vertical; MPN WAGO 2601-3102 (lever); LCSC C20252913
J10: microSD (hinged lid); microSD_HC_Molex_47219-2001; MPN Molex 47219-2001 (hinge lid - will not 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; LCSC C164170
J11: QWIIC (GPS / rangefinder); JST_SH_SM04B-SRSS-TB_1x04-1MP_P1.00mm_Horizontal; MPN JST SM04B-SRSS-TB; LCSC C160404
JP1: I2C PULLUP 5V (2-3 joined); SolderJumper-3_P1.3mm_Open_RoundedPad1.0x1.5mm; MPN solder jumper (no part)
L1: 2.2uH; L_Bourns_SRN6045TA; MPN Bourns SRN6045TA-2R2Y (2.2uH, 6A); LCSC C1332316
Q1, Q2, Q3, Q4, Q5: AO3400A; SOT-23; MPN AO3400A; LCSC C20917
Q6, Q7: BSS138; SOT-23; MPN Diodes BSS138-7-F; LCSC C40912
R1, R4, R6, R7, R12, R15, R16, R19, R20, R23, R24, R27, R28, R31: 100k; R_0603_1608Metric; LCSC C25803
R2, R13, R17, R21, R25, R29: 33k; R_0603_1608Metric; LCSC C4216
R3: 1k; R_0603_1608Metric; LCSC C21190
R5: 18k; R_0603_1608Metric; LCSC C25810
R8, R9, R10: 220; R_0603_1608Metric; LCSC C22962
R11: 47k; R_0603_1608Metric; LCSC C25819
R14, R18, R22, R26, R30: 100; R_0603_1608Metric; LCSC C22775
R32, R33, R34, R35: 4.7k; R_0603_1608Metric; LCSC C23162
R36, R37, R38, R39, R40: 10k; R_0603_1608Metric; LCSC C25804
SW1: POWER; SW_CK_JS202011AQN_DPDT_Angled; MPN C&K JS202011AQN; LCSC C221662
TP1: VLOGIC; TestPoint_Pad_D1.5mm
TP2: VSERVO; TestPoint_Pad_D1.5mm
TP3: +3V3; TestPoint_Pad_D1.5mm
TP4: GND; TestPoint_Pad_D1.5mm
TP5: VBAT; TestPoint_Pad_D1.5mm
U1: AMS1117-3.3; SOT-223-3_TabPin2; MPN AMS1117-3.3; LCSC C6186
U2: TPS563200; SOT-23-6; MPN TI TPS563200DDCR; LCSC C97253
U3: LSM6DSO32; LGA-14_3x2.5mm_P0.5mm_LayoutBorder3x4y; MPN ST LSM6DSO32TR (+/-32g, 2000dps; pin-co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; LCSC C1864162
U4: MS5607-02BA03; LGA-8_3x5mm_P1.25mm; MPN TE MS5607-02BA03 (pin-compatible MS5611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; LCSC C97627
U5: 74LVC125A; SOIC-14_3.9x8.7mm_P1.27mm; MPN TI SN74LVC125ADR (5V-tolerant inputs, r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; LCSC C7661

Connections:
+3V3: C4.1, C5.1, C20.1, C21.1, C22.1, C23.1, C24.1, J10.4 (VDD), J11.2, JP1.1 (A), Q6.1 (G), Q7.1 (G), R3.1, R34.2, R35.2, R36.2, R37.2, R38.2, R39.2, R40.2, TP3.1, U1.2 (VO), U3.5 (VDDIO), U3.8 (VDD), U3.12 (CS), U4.1 (VDD), U4.2 (PS), U5.13, U5.14 (VCC)
ARM_SENSE: A1.26 (A7), C14.1, R12.2, R13.1
BUCK_BST: C9.1, U2.6 (VBST)
BUCK_EN: R6.2, R7.1, U2.5 (EN)
BUCK_FB: R4.2, R5.1, U2.4 (VFB)
BUCK_SW: C9.2, L1.1, U2.2 (SW)
BUZZER_CMD: A1.12 (D9), R30.1
BUZ_G: Q5.1 (G), R30.2, R31.1
BUZ_N: BZ1.2 (-), D3.2 (A), Q5.3 (D)
CONT1: A1.19 (A0), C16.1, R16.2, R17.1
CONT2: A1.20 (A1), C17.1, R20.2, R21.1
CONT3: A1.21 (A2), C18.1, R24.2, R25.1
CONT4: A1.22 (A3), C19.1, R28.2, R29.1
GND: A1.4 (GND), A1.29 (GND), C1.2, C2.2, C3.2, C4.2, C5.2, C6.2, C7.2, C8.2, C10.2, C11.2, C12.2, C13.2, C14.2, C15.2, C16.2, C17.2, C18.2, C19.2, C20.2, C21.2, C22.2, C23.2, C24.2, D2.1 (K), J1.1, J2.3, J3.3, J4.3, J10.6 (VSS), J10.9 (SHIELD), J11.1, Q1.2 (S), Q2.2 (S), Q3.2 (S), Q4.2 (S), Q5.2 (S), R2.2, R5.2, R7.2, R13.2, R15.2, R17.2, R19.2, R21.2, R23.2, R25.2, R27.2, R29.2, R31.2, TP4.1, U1.1 (GND), U2.1 (GND), U3.1 (SDO/SA0), U3.2 (SDX), U3.3 (SCX), U3.6 (GND), U3.7 (GND), U4.3 (GND), U4.4 (CSB), U4.5 (CSB), U5.1, U5.4, U5.7 (GND), U5.10, U5.12
LED_PWR: D2.2 (A), R3.2
MISO: A1.15 (D12), J10.7 (DAT0), R40.1
MOSI_5V: A1.14 (D11), U5.5
NANO_5V: A1.27 (+5V), JP1.2 (C), JP1.3 (B), R32.2, R33.2
PYRO1_CMD: A1.5 (D2), R14.1
PYRO1_G: Q1.1 (G), R14.2, R15.1
PYRO1_N: J6.2, Q1.3 (D), R16.1
PYRO2_CMD: A1.7 (D4), R18.1
PYRO2_G: Q2.1 (G), R18.2, R19.1
PYRO2_N: J7.2, Q2.3 (D), R20.1
PYRO3_CMD: A1.9 (D6), R22.1
PYRO3_G: Q3.1 (G), R22.2, R23.1
PYRO3_N: J8.2, Q3.3 (D), R24.1
PYRO4_CMD: A1.11 (D8), R26.1
PYRO4_G: Q4.1 (G), R26.2, R27.1
PYRO4_N: J9.2, Q4.3 (D), R28.1
SCK_5V: A1.16 (D13), U5.2
SCL: J11.4, Q7.2 (S), R35.1, U3.13 (SCL), U4.8 (SCLK)
SCL_H: A1.24 (A5), Q7.3 (D), R33.1
SDA: J11.3, Q6.2 (S), R34.1, U3.14 (SDA), U4.7 (SDI/SDA)
SDA_H: A1.23 (A4), Q6.3 (D), R32.1
SD_CS: J10.2 (DAT3/CD), R37.1, U5.8
SD_CS_5V: A1.13 (D10), R36.1, U5.9
SD_DAT1: J10.8 (DAT1), R38.1
SD_DAT2: J10.1 (DAT2), R39.1
SD_MOSI: J10.3 (CMD), U5.6
SD_SCK: J10.5 (CLK), U5.3
SERVO_AUX: A1.10 (D7), R10.1
SERVO_AUX_OUT: J4.1, R10.2
SERVO_X: A1.6 (D3), R8.1
SERVO_X_OUT: J2.1, R8.2
SERVO_Y: A1.8 (D5), R9.1
SERVO_Y_OUT: J3.1, R9.2
VBAT: C6.1, C7.1, C8.1, D1.2 (A), J1.2, J5.2, R1.1, TP5.1, U2.3 (VIN)
VBAT_D: D1.1 (K), SW1.2 (B), SW1.5 (B)
VBAT_SENSE: A1.25 (A6), C3.1, R1.2, R2.1
VLOGIC: A1.30 (VIN), C1.1, C2.1, R6.1, R11.1, SW1.3 (C), SW1.4 (A), TP1.1, U1.3 (VI)
VPYRO: C15.1, J5.1, J6.1, J7.1, J8.1, J9.1, R11.2, R12.1
VSERVO: BZ1.1 (+), C10.1, C11.1, C12.1, C13.1, D3.1 (K), J2.2, J3.2, J4.2, L1.2, R4.1, TP2.1

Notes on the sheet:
POWER INPUT, SWITCH, HOLD-UP & 3.3V
SERVO 5V BUCK & SERVO OUTPUTS
ARDUINO NANO (SOCKETED)
PYRO CHANNELS (LOW-SIDE, ARM PLUG, CONTINUITY)
IMU, BAROMETER, I2C LEVEL SHIFT, QWIIC
microSD LOGGING
BUZZER
SAFETY: pyros cannot fire until the XT30 ARM PLUG (J5) is inserted. R11 (47k) lets the Nano read continuity while DISARMED (<0.2 mA, far below no-fire).
Every MOSFET gate has a 100k pull-down: channels stay OFF while the Nano boots/resets/is unplugged. CONTx drops to 0V when the igniter burns through = exact ignition time.
Power switch feeds logic through D1 into 470uF hold-up cap C1, so igniter current (5-12 A) sagging the LiPo cannot reset the Nano.
Servos have their own 5V/3A buck (U2) straight from the battery: servo stall current never touches the logic supply.
BSS138 shifters keep a 5V classic Nano from over-driving the 3.3V sensors; transparent for a 3.3V Nano ESP32.
74LVC125 converts 5V SPI down to 3.3V for the card. Hinged-lid socket so the card cannot eject on landing.

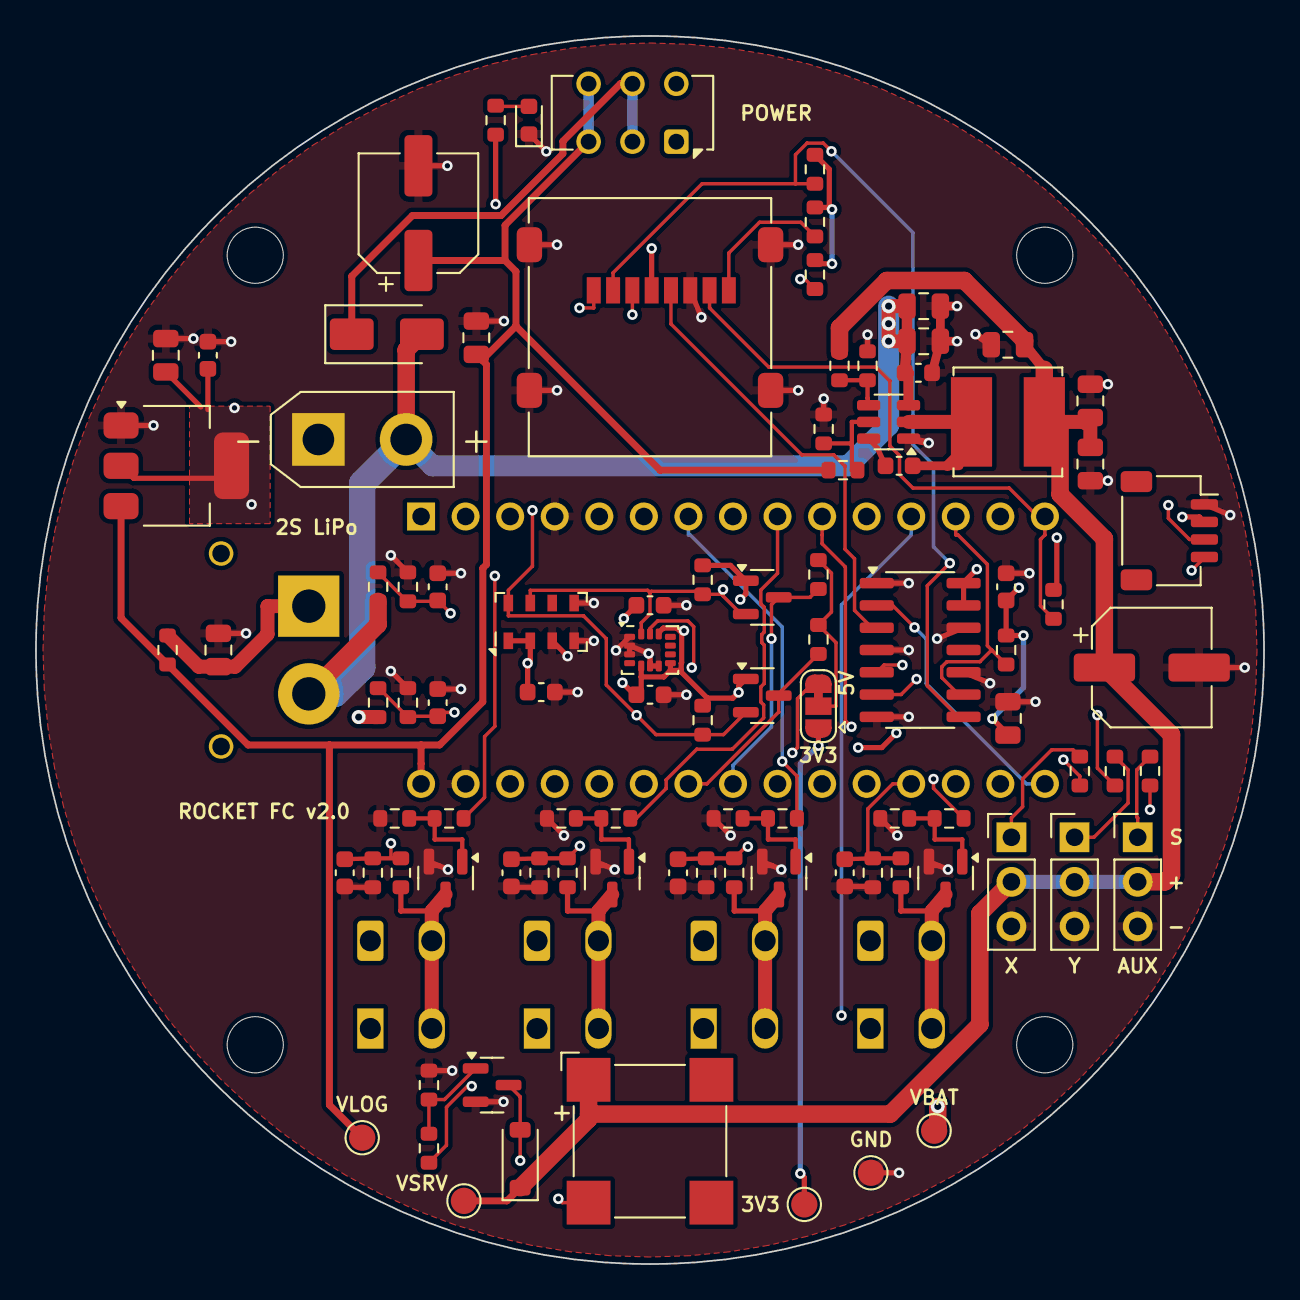
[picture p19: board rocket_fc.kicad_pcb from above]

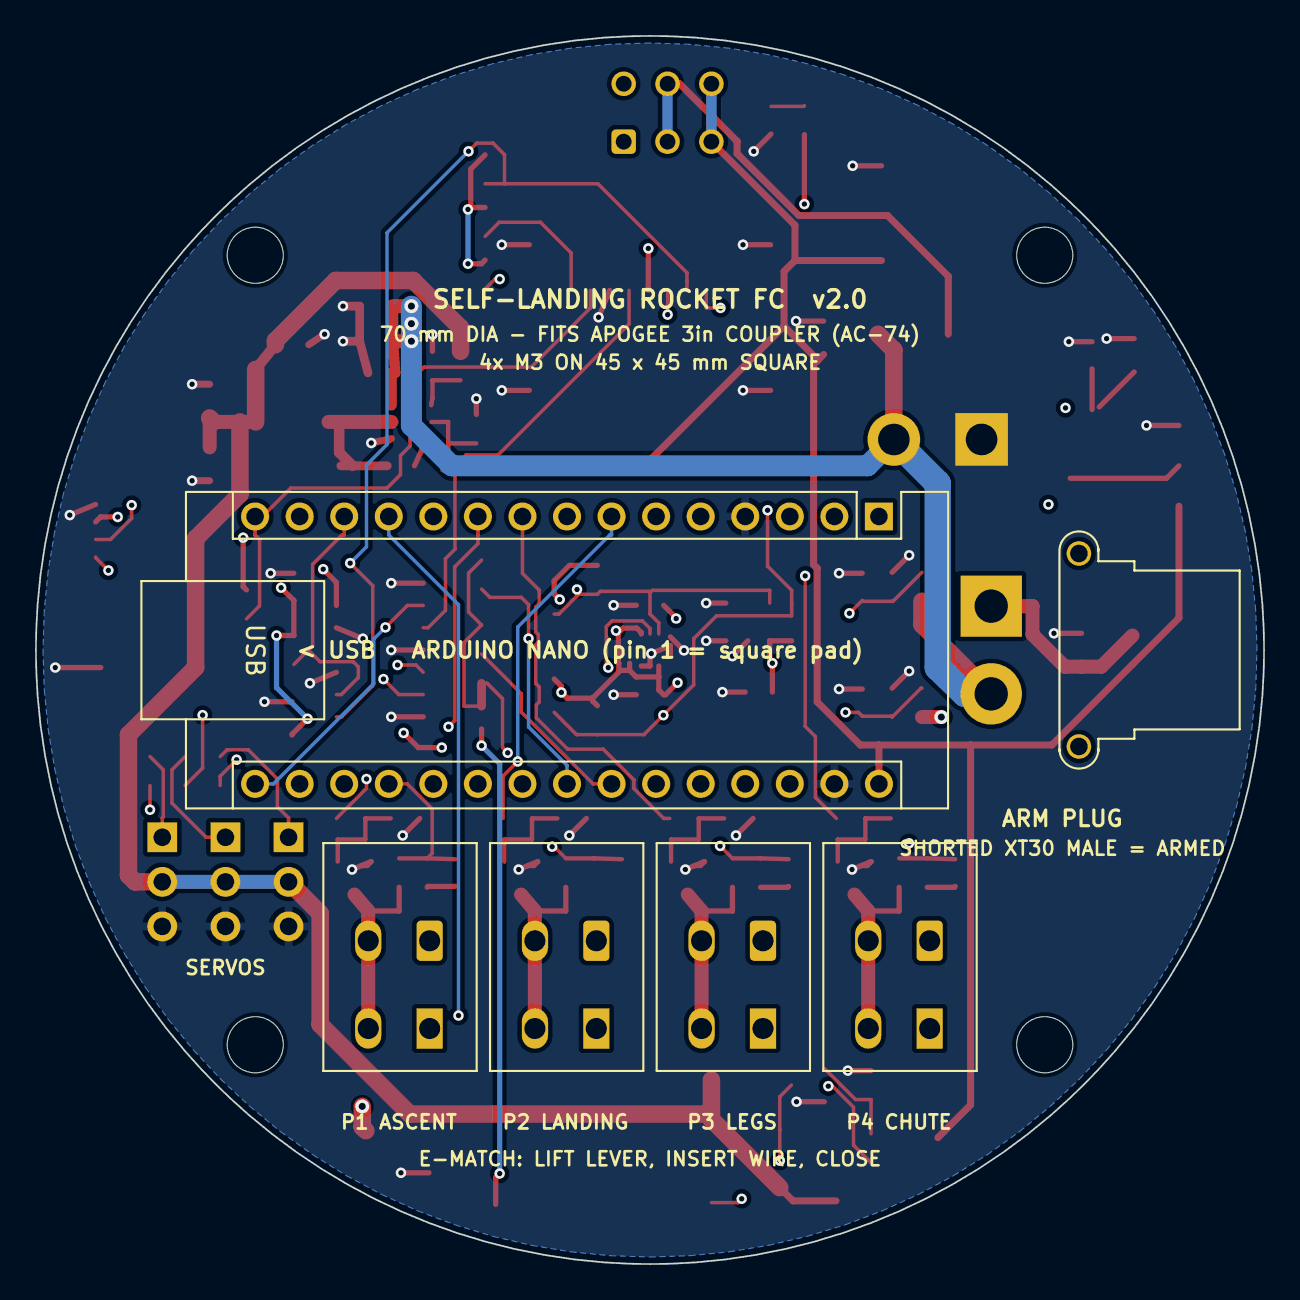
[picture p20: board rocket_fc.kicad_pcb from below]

Board: 4 copper layers, 70.0 x 70.0 mm, 104 parts (6 on the bottom side), 53 nets.

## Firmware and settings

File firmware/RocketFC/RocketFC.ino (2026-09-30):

// RocketFC v2.1 flight software  -  Arduino Nano (ATmega328P, 5 V, 16 MHz)
// Libraries: Wire, SPI, SD, Servo (all built into the Arduino IDE).
#include <Wire.h>
#include <SPI.h>
#include <SD.h>
#include <Servo.h>

const float G = 9.80665;
// ======================= CONFIG: edit these =======================
#define MODE_CHUTE_TEST 0            // TVC ascent, chute at apogee (fly this first)
#define MODE_LANDING    1            // TVC ascent, landing burn with the 2nd F15
const uint8_t FLIGHT_MODE = MODE_CHUTE_TEST;

// TVC mount (set with the 'sweep' and 'tvc' bench commands)
const int   X_CENTER_US = 1500, Y_CENTER_US = 1500;
const float US_PER_DEG  = 30.0;      // servo microseconds per 1 deg of motor tilt
const float GIMBAL_MAX  = 5.0;       // deg
const int8_t SIGN_X = 1, SIGN_Y = 1; // flip to -1 if a nozzle moves the wrong way
const bool  SWAP_XY = false;         // true if servo X actually tilts about the IMU Y axis
const float KP = 0.30, KI = 0.05, KD = 0.08;   // gimbal deg per: deg, deg*s, deg/s

// chute servo (Servo.write degrees)
const uint8_t CHUTE_LOCK = 90, CHUTE_OPEN = 0;

// flight events
const float    LAUNCH_G      = 1.5;   // F15 peaks ~2.3 g on a 1.1 kg rocket; 1.5 g catches it
const uint16_t LAUNCH_MS     = 50;
const float    CONFIRM_ALT   = 3.0;   // must climb this high within CONFIRM_MS or it was a bump
const uint32_t CONFIRM_MS    = 2500;
const uint32_t BURN_MAX_MS   = 4000;  // F15 burns ~3.5 s
const uint32_t APOGEE_MAX_MS = 9000;  // backup: chute no later than this after liftoff
const float    LEGS_ALT      = 20.0;  // chute mode: release legs below this (m AGL)
const uint16_t EMATCH_MS = 1000, BURNWIRE_MS = 2500;

// landing mode: the F15 can't throttle, so the burn must END at the ground.
// It only works when apogee matches the landing mass (0.95 kg needs ~46 m, 1.0 kg ~37 m);
// otherwise the computer uses the chute instead.
const float LAND_MASS_KG = 0.95;     // WEIGH IT: total mass at landing ignition (kg)
const float IGN_DELAY_S  = 0.35;     // command -> thrust; measure with a static test ('fire2')
const float LAND_MARGIN  = -0.5;     // burn ends just "below" ground: touch down while still braking
const float CDA          = 0.0027;   // drag area Cd*A (m^2); 3in tube falling tail-first ~0.6 x 0.0046
const float MAX_TOUCHDOWN = 3.0;     // predicted touchdown faster than this -> chute instead
const float MAX_TILT     = 25.0;     // tilted more than this at apogee/ignition -> chute
const float F15_I = 49.6, F15_J = 88.6, F15_TB = 3.45;   // Estes F15: impulse, 1st moment, burn time
const float DV_BURN = F15_I / LAND_MASS_KG - G * F15_TB;                 // speed the burn removes
const float S_BURN  = F15_J / LAND_MASS_KG - 0.5f * G * F15_TB * F15_TB; // climb the burn adds from rest
// ==================================================================

// Pins (RocketFC v2.1)
const uint8_t PYRO_PIN[4] = {2, 4, 6, 8};       // P1 ascent, P2 landing, P3 legs, P4 spare
const uint8_t CONT_PIN[4] = {A0, A1, A2, A3};
enum { P_ASCENT, P_LANDING, P_LEGS, P_SPARE };
const uint8_t PIN_SX = 3, PIN_SY = 5, PIN_CHUTE = 7, PIN_BUZZ = 9, PIN_SD = 10;
const uint8_t IMU = 0x6A, BARO = 0x77;

enum State : uint8_t { PAD, BOOST, COAST, CHUTE_DESCENT, WAIT_IGNITE, LAND_BURN, LANDED };
State state = PAD;

Servo sx, sy, chute;
File logFile;
bool imuOK, baroOK, sdOK, tvcTest;

// sensors
float ax, ay, az, gx, gy, gz;          // g and deg/s (bias removed)
float gbx, gby, gbz;                   // gyro bias
float lax, lay, laz = 1;               // low-passed accel (pad levelling)
uint16_t C[7];                         // baro PROM
float pressure, p0, baroAlt;
bool baroNew;

// state estimate
float q0 = 1, q1, q2, q3;              // attitude, body -> world
float tiltX, tiltY, tilt;              // deg
float alt, vel, maxAlt;                // m, m/s (fused baro + accel)
float ix, iy;                          // PID integrators
int   usX = X_CENTER_US, usY = Y_CENTER_US;

// timing / events
uint32_t tLaunch, tEvent, tCond, lastCtl, lastLog, lastFlush, lastBeep, lastAdc;
uint32_t pyroEnd[4];
uint8_t  pyroFired, contMask;
bool     armed, chuteOpen, legsDone, confirmed, thrustSeen;
float    vbat;

// ------------------------------------------------------------------ I2C helpers
bool i2cCmd(uint8_t addr, uint8_t c) {
  Wire.beginTransmission(addr); Wire.write(c);
  return Wire.endTransmission() == 0;
}
bool i2cWrite(uint8_t addr, uint8_t reg, uint8_t val) {
  Wire.beginTransmission(addr); Wire.write(reg); Wire.write(val);
  return Wire.endTransmission() == 0;
}
bool i2cRead(uint8_t addr, uint8_t reg, uint8_t* buf, uint8_t n) {
  Wire.beginTransmission(addr); Wire.write(reg);
  if (Wire.endTransmission(false)) return false;
  if (Wire.requestFrom(addr, n) != n) return false;
  for (uint8_t i = 0; i < n; i++) buf[i] = Wire.read();
  return true;
}

// ------------------------------------------------------------------ LSM6DSO32
bool imuInit() {
  uint8_t id = 0;
  if (!i2cRead(IMU, 0x0F, &id, 1) || id != 0x6C) return false;
  i2cWrite(IMU, 0x12, 0x01); delay(20);   // CTRL3_C: software reset
  i2cWrite(IMU, 0x12, 0x44);              // block data update + auto-increment
  i2cWrite(IMU, 0x10, 0x74);              // CTRL1_XL: 833 Hz, +/-32 g
  i2cWrite(IMU, 0x11, 0x7C);              // CTRL2_G : 833 Hz, +/-2000 dps
  return true;
}
float rgx, rgy, rgz;                      // raw gyro (deg/s) for bias tracking
bool imuRead() {
  uint8_t b[12];
  if (!i2cRead(IMU, 0x22, b, 12)) return false;
  int16_t r[6];
  for (uint8_t i = 0; i < 6; i++) r[i] = (int16_t)((uint16_t)b[2 * i + 1] << 8 | b[2 * i]);
  rgx = r[0] * 0.070f; rgy = r[1] * 0.070f; rgz = r[2] * 0.070f;
  gx = rgx - gbx; gy = rgy - gby; gz = rgz - gbz;
  ax = r[3] * 0.000976f; ay = r[4] * 0.000976f; az = r[5] * 0.000976f;
  return true;
}

// ------------------------------------------------------------------ MS5607 (non-blocking)
bool baroInit() {
  if (!i2cCmd(BARO, 0x1E)) return false;
  delay(5);
  for (uint8_t i = 1; i <= 6; i++) {
    uint8_t b[2];
    if (!i2cRead(BARO, 0xA0 + 2 * i, b, 2)) return false;
    C[i] = (uint16_t)b[0] << 8 | b[1];
  }
  return C[1] != 0 && C[1] != 0xFFFF;
}
uint32_t D1, D2;
uint8_t baroStep, baroCount;
uint32_t baroT;
void baroService() {                      // OSR1024 (2.3 ms); temperature every 20th sample
  if (!baroOK || micros() - baroT < 2600) return;
  uint8_t b[3];
  if (baroStep) {
    if (!i2cRead(BARO, 0x00, b, 3)) { baroStep = 0; return; }
    uint32_t v = (uint32_t)b[0] << 16 | (uint16_t)b[1] << 8 | b[2];
    if (baroStep == 2) D2 = v;
    else if (D2) {
      D1 = v;
      float dT   = (float)D2 - C[5] * 256.0f;              // MS5607 datasheet, in float
      float T    = 2000 + dT * C[6] / 8388608.0f;
      float off  = C[2] * 131072.0f + C[4] * dT / 64.0f;
      float sens = C[1] * 65536.0f + C[3] * dT / 128.0f;
      if (T < 2000) { float t = T - 2000; off -= 61 * t * t / 16; sens -= 2 * t * t; }   // cold day
      pressure = ((float)D1 * sens / 2097152.0f - off) / 32768.0f;                        // Pa
      if (p0 > 0) {                        // hypsometric 8434*ln(p0/P), series form (<1 cm error below 300 m)
        float x = (p0 - pressure) / p0;
        baroAlt = 8434.0f * x * (1 + x * (0.5f + x * 0.3333f));
      }
      baroNew = true;
    }
  }
  bool temp = (baroCount++ % 20 == 0);
  i2cCmd(BARO, temp ? 0x54 : 0x44);
  baroStep = temp ? 2 : 1;
  baroT = micros();
}

// ------------------------------------------------------------------ attitude
void levelFromAccel() {                   // quaternion that rotates measured "up" onto world +Z
  float n = sqrt(lax * lax + lay * lay + laz * laz);
  if (n < 0.5f) return;
  float vx = lax / n, vy = lay / n, vz = laz / n;
  float w = 1 + vz, x = vy, y = -vx;
  float m = sqrt(w * w + x * x + y * y);
  if (m < 1e-3f) return;                  // upside down: keep last
  q0 = w / m; q1 = x / m; q2 = y / m; q3 = 0;
}
void integrateGyro(float dt) {
  const float k = 0.5f * dt * 0.0174533f;
  float wx = gx * k, wy = gy * k, wz = gz * k;
  float n0 = q0 - q1 * wx - q2 * wy - q3 * wz;
  float n1 = q1 + q0 * wx + q2 * wz - q3 * wy;
  float n2 = q2 + q0 * wy + q3 * wx - q1 * wz;
  float n3 = q3 + q0 * wz + q1 * wy - q2 * wx;
  float n = 1.0f / sqrt(n0 * n0 + n1 * n1 + n2 * n2 + n3 * n3);
  q0 = n0 * n; q1 = n1 * n; q2 = n2 * n; q3 = n3 * n;
}
float fatan2(float y, float x) {          // compact atan2, error < 0.3 deg
  float ay = fabs(y), ax = fabs(x), a;
  if (ax + ay < 1e-9f) return 0;
  if (ax >= ay) { float r = ay / ax; a = r * (0.9724f - 0.1919f * r * r); }
  else          { float r = ax / ay; a = 1.5708f - r * (0.9724f - 0.1919f * r * r); }
  if (x < 0) a = 3.14159f - a;
  return y < 0 ? -a : a;
}
float ux, uy, uz = 1;                     // world "up" seen in the body frame
void updateTilt() {
  ux = 2 * (q1 * q3 - q0 * q2); uy = 2 * (q2 * q3 + q0 * q1); uz = 1 - 2 * (q1 * q1 + q2 * q2);
  tiltX = fatan2(uy, uz) * 57.2958f;
  tiltY = fatan2(-ux, uz) * 57.2958f;
  tilt  = fatan2(sqrt(ux * ux + uy * uy), uz) * 57.2958f;
}
float verticalAccel() {                   // m/s^2, world frame, gravity removed (call after updateTilt)
  return (ux * ax + uy * ay + uz * az - 1.0f) * G;
}
void fuseAltitude(float dt, bool useAccel) {
  if (useAccel) { vel += verticalAccel() * dt; alt += vel * dt; }
  if (baroNew) {
    baroNew = false;
    float e = baroAlt - alt;
    alt += (useAccel ? 0.10f : 0.30f) * e;
    vel += (useAccel ? 0.05f : 0.10f) * e;
  }
  if (alt > maxAlt) maxAlt = alt;
}

// ------------------------------------------------------------------ landing burn prediction
float burnoutAlt(float h, float v) {      // altitude at landing-motor burnout if we fire right now
  float v1 = v - G * IGN_DELAY_S;
  float h1 = h + v * IGN_DELAY_S - 0.5f * G * IGN_DELAY_S * IGN_DELAY_S;
  // drag during the burn stops us higher than the vacuum answer (factor fitted in simulation)
  return h1 + v1 * F15_TB + S_BURN + (0.6125f * CDA / LAND_MASS_KG) * v1 * v1 * (F15_TB * F15_TB * 0.28f);
}
float predictTouchdown(float H) {         // falling from apogee H and firing on time: speed at burnout
  // fall speed u at motor start solves  u^2/2g + u*TB = H + S - margin  (burn ends at the ground)
  float u = G * (sqrt(F15_TB * F15_TB + 2 * (H + S_BURN - LAND_MARGIN) / G) - F15_TB);
  return DV_BURN - u;                     // m/s, + = up
}

// ------------------------------------------------------------------ TVC
void tvcCenter() {
  ix = iy = 0; usX = X_CENTER_US; usY = Y_CENTER_US;
  sx.writeMicroseconds(usX); sy.writeMicroseconds(usY);
}
void tvcControl(float dt) {
  ix = constrain(ix + tiltX * dt, -20.0f, 20.0f);
  iy = constrain(iy + tiltY * dt, -20.0f, 20.0f);
  float cx = -(KP * tiltX + KI * ix + KD * gx);          // correction about body X
  float cy = -(KP * tiltY + KI * iy + KD * gy);          // correction about body Y
  cx = constrain(cx, -GIMBAL_MAX, GIMBAL_MAX);
  cy = constrain(cy, -GIMBAL_MAX, GIMBAL_MAX);
  if (SWAP_XY) { float t = cx; cx = cy; cy = t; }
  usX = X_CENTER_US + (int)(SIGN_X * cx * US_PER_DEG);
  usY = Y_CENTER_US + (int)(SIGN_Y * cy * US_PER_DEG);
  sx.writeMicroseconds(usX); sy.writeMicroseconds(usY);
}

// ------------------------------------------------------------------ pyro, chute, ADC, buzzer
void fire(uint8_t ch, uint16_t ms) {
  digitalWrite(PYRO_PIN[ch], HIGH);
  pyroEnd[ch] = millis() + ms; if (!pyroEnd[ch]) pyroEnd[ch] = 1;
  pyroFired |= 1 << ch;
  Serial.print(F("FIRE P")); Serial.println(ch + 1);
}
void pyroService() {
  for (uint8_t i = 0; i < 4; i++)
    if (pyroEnd[i] && (int32_t)(millis() - pyroEnd[i]) >= 0) { digitalWrite(PYRO_PIN[i], LOW); pyroEnd[i] = 0; }
}
void deployChute() {
  if (chuteOpen) return;
  chute.write(CHUTE_OPEN); chuteOpen = true;
  Serial.println(F("CHUTE"));
}
void readAdc() {
  contMask = 0;
  for (uint8_t i = 0; i < 4; i++) if (analogRead(CONT_PIN[i]) > 80) contMask |= 1 << i;
  armed = analogRead(A7) > 300;                       // ~2.1 V when the ARM plug is in
  vbat  = analogRead(A6) * (5.0f / 1023.0f) * (133.0f / 33.0f);
}
// buzzer: Timer2 toggles D9 (PB1); much smaller than tone()
volatile uint16_t buzzLeft;
ISR(TIMER2_COMPA_vect) {
  if (buzzLeft) { PINB = _BV(1); buzzLeft--; }
  else { TIMSK2 = 0; PORTB &= ~_BV(1); }
}
void beep(uint16_t f, uint16_t ms) {
  TIMSK2 = 0;
  TCCR2A = _BV(WGM21); TCCR2B = _BV(CS22);              // CTC, 16 MHz / 64 = 250 kHz
  OCR2A = (uint8_t)(125000UL / f - 1);                   // valid for 490 Hz .. 60 kHz
  TCNT2 = 0;
  buzzLeft = (uint32_t)f * ms / 500;                     // two toggles per cycle
  TIMSK2 = _BV(OCIE2A);
}
void noBeep() { buzzLeft = 0; }

// ------------------------------------------------------------------ logging (CSV)
void openLog() {
  char name[] = "FLT00.CSV";
  for (uint8_t i = 0; i < 100; i++) {
    name[3] = '0' + i / 10; name[4] = '0' + i % 10;
    if (!SD.exists(name)) break;
  }
  logFile = SD.open(name, FILE_WRITE);
  if (!logFile) { sdOK = false; return; }
  logFile.println(F("ms,st,alt_cm,vel_cms,ax_mg,ay_mg,az_mg,gx_ddps,gy_ddps,gz_ddps,tx_cdeg,ty_cdeg,sx_us,sy_us,vb_mV,cont,fired,chute"));
  logFile.flush();
  Serial.print(F("log: ")); Serial.println(name);
}
void logLine() {
  if (!sdOK || !logFile) return;
  long v[17] = { (long)millis(), state, (long)(alt * 100), (long)(vel * 100),
                 (long)(ax * 1000), (long)(ay * 1000), (long)(az * 1000),
                 (long)(gx * 10), (long)(gy * 10), (long)(gz * 10),
                 (long)(tiltX * 100), (long)(tiltY * 100), usX, usY,
                 (long)(vbat * 1000), contMask, pyroFired };
  for (uint8_t i = 0; i < 17; i++) { logFile.print(v[i]); logFile.print(','); }
  logFile.println(chuteOpen);
}

// ------------------------------------------------------------------ bench commands (USB serial, PAD only)
char cmd[12]; uint8_t cmdLen;
void printStatus() {
  Serial.print(F("state ")); Serial.print(state);   // 0 PAD 1 BOOST 2 COAST 3 CHUTE 4 WAIT_IGN 5 LAND_BURN 6 LANDED
  Serial.print(F(" | IMU/BARO/SD (1=ok) ")); Serial.print(imuOK); Serial.print(baroOK); Serial.println(sdOK);
  Serial.print(F("batt mV ")); Serial.print((int)(vbat * 1000)); Serial.print(F(" | ARM plug ")); Serial.println(armed ? F("IN") : F("out"));
  Serial.print(F("continuity P1..P4: "));
  for (uint8_t i = 0; i < 4; i++) Serial.print(contMask & (1 << i) ? F("Y ") : F("- "));
  Serial.println();
  Serial.print(F("accel mg ")); Serial.print((int)(ax * 1000)); Serial.print(' '); Serial.print((int)(ay * 1000)); Serial.print(' '); Serial.print((int)(az * 1000));
  Serial.print(F(" | tilt X/Y deg ")); Serial.print((int)tiltX); Serial.print(' '); Serial.print((int)tiltY);
  Serial.print(F(" | alt cm ")); Serial.print((long)(alt * 100)); Serial.print(F(" | P Pa ")); Serial.println((long)pressure);
}
void servoSweep() {
  Serial.println(F("sweep: X then Y, +/- max"));
  const int d = (int)(GIMBAL_MAX * US_PER_DEG);
  int seq[] = {0, d, -d, 0};
  for (uint8_t i = 0; i < 4; i++) { sx.writeMicroseconds(X_CENTER_US + seq[i]); delay(600); }
  for (uint8_t i = 0; i < 4; i++) { sy.writeMicroseconds(Y_CENTER_US + seq[i]); delay(600); }
}
void handleCommand() {
  if (!strcmp(cmd, "s") || !strcmp(cmd, "status")) printStatus();
  else if (!strcmp(cmd, "sweep")) servoSweep();
  else if (!strcmp(cmd, "tvc"))  { tvcTest = !tvcTest; if (!tvcTest) tvcCenter(); Serial.println(tvcTest ? F("TVC test ON: lean the rocket") : F("TVC test off")); }
  else if (!strcmp(cmd, "open")) { chute.write(CHUTE_OPEN); Serial.println(F("chute OPEN")); }
  else if (!strcmp(cmd, "lock")) { chute.write(CHUTE_LOCK); chuteOpen = false; Serial.println(F("chute LOCK")); }
  else if (!strcmp(cmd, "beep")) beep(4000, 300);
  else if (!strncmp(cmd, "fire", 4) && cmd[4] >= '1' && cmd[4] <= '4' && !cmd[5]) {
    if (!armed) Serial.println(F("ARM plug is out - nothing will fire"));
    fire(cmd[4] - '1', cmd[4] == '3' ? BURNWIRE_MS : EMATCH_MS);
  }
  else Serial.println(F("cmds: s | sweep | tvc | open | lock | beep | fire1..fire4"));
}
void serialService() {
  while (Serial.available()) {
    char c = Serial.read();
    if (c == '\n' || c == '\r') { if (cmdLen) { cmd[cmdLen] = 0; handleCommand(); cmdLen = 0; } }
    else if (cmdLen < sizeof(cmd) - 1) cmd[cmdLen++] = c;
  }
}
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
void loop() {
  baroService();
  pyroService();
  uint32_t now = micros();
  if (now - lastCtl < 5000) return;
  float dt = (now - lastCtl) * 1e-6f;
  lastCtl = now;
  if (dt > 0.1f) dt = 0.1f;                // after an SD stall, don't over-integrate
  uint32_t ms = millis();
  bool ok = imuOK && imuRead();

  switch (state) {
    case PAD: {
      if (ok) {                              // track gyro bias + level while sitting still
        float gmag = fabs(gx) + fabs(gy) + fabs(gz);
        if (az < 1.3f && gmag < 6) {
          gbx += 0.002f * (rgx - gbx); gby += 0.002f * (rgy - gby); gbz += 0.002f * (rgz - gbz);
          lax += 0.02f * (ax - lax); lay += 0.02f * (ay - lay); laz += 0.02f * (az - laz);
          levelFromAccel();
        } else integrateGyro(dt);
        updateTilt();
      }
      if (baroNew && fabs(vel) < 1 && launchCount == 0) {   // slow ground-pressure tracking
        p0 = p0 * 0.999f + pressure * 0.001f; baroAlt = 0;
      }
      fuseAltitude(dt, false); vel = 0;
      serialService();
      if (tvcTest) tvcControl(dt);
      if (ms - lastAdc > 200) { lastAdc = ms; readAdc(); }
      bool ready = imuOK && baroOK && sdOK && tilt < 30 && vbat > 7.0f;   // beeps only
      if (ms - lastBeep > 3000) {            // pad beeps: high chirp = ready, low buzz = not ready
        lastBeep = ms;
        beep(ready ? 3000 : 700, ready ? (armed ? 300 : 80) : 400);
      }
      if (ok && tilt < 30 && !tvcTest && az > LAUNCH_G) {   // never blocked by battery/SD
        if (++launchCount * 5 >= LAUNCH_MS) {
          state = BOOST; tLaunch = ms - LAUNCH_MS; alt = 0; vel = 0; maxAlt = 0; ix = iy = 0; confirmed = false;
          noBeep();
          Serial.println(F("LIFTOFF"));
        }
      } else launchCount = 0;
      break;
    }
    case BOOST:
      if (ok) { integrateGyro(dt); updateTilt(); tvcControl(dt); }
      fuseAltitude(dt, ok);
      if ((ms - tLaunch > 500 && az < 0.3f) || ms - tLaunch > BURN_MAX_MS) {
        state = COAST; tvcCenter(); Serial.println(F("BURNOUT"));
      }
      break;
    case COAST:
      if (ok) { integrateGyro(dt); updateTilt(); }
      fuseAltitude(dt, ok);
      if (vel < 0) { if (!tCond) tCond = ms; } else tCond = 0;
      if (confirmed && ((tCond && ms - tCond > 200 && ms - tLaunch > 2000) || ms - tLaunch > APOGEE_MAX_MS)) {
        tEvent = ms; tCond = 0;
        Serial.print(F("APOGEE cm ")); Serial.println((long)(maxAlt * 100));
        float vtd = predictTouchdown(maxAlt);
        if (FLIGHT_MODE == MODE_LANDING) { Serial.print(F("predicted touchdown cm/s ")); Serial.println((long)(vtd * 100)); }
        if (FLIGHT_MODE == MODE_LANDING && vtd > -MAX_TOUCHDOWN && vtd < 0.5f && tilt <= MAX_TILT && ms - tLaunch <= APOGEE_MAX_MS)
          state = WAIT_IGNITE;
        else { deployChute(); state = CHUTE_DESCENT; }
      }
      break;
    case CHUTE_DESCENT:
      if (ok) { integrateGyro(dt); updateTilt(); }
      fuseAltitude(dt, ok);
      if (!legsDone && alt < LEGS_ALT && ms - tEvent > 1000) { fire(P_LEGS, BURNWIRE_MS); legsDone = true; }
      break;
    case WAIT_IGNITE: {
      if (ok) { integrateGyro(dt); updateTilt(); }
      fuseAltitude(dt, ok);
      // fire when a burn started now (after the igniter delay) would end right at the ground
      if (vel < 0 && burnoutAlt(alt, vel) <= LAND_MARGIN) {
        if (tilt > MAX_TILT) { deployChute(); state = CHUTE_DESCENT; Serial.println(F("ABORT: tilt")); break; }
        fire(P_LANDING, EMATCH_MS); fire(P_LEGS, BURNWIRE_MS); legsDone = true;
        state = LAND_BURN; tEvent = ms; ix = iy = 0;
      } else if (alt < 8) { deployChute(); state = CHUTE_DESCENT; Serial.println(F("ABORT: never triggered")); }
      break;
    }
    case LAND_BURN:
      if (ok) { integrateGyro(dt); updateTilt(); tvcControl(dt); }
      fuseAltitude(dt, ok);
      if (az > 1.3f) thrustSeen = true;
      if (!thrustSeen && ms - tEvent > (uint32_t)(IGN_DELAY_S * 1000) + 800) {           // no light -> chute
        deployChute(); tvcCenter(); state = CHUTE_DESCENT; Serial.println(F("ABORT: no ignition"));
      }
      if (thrustSeen && ms - tEvent > 4500 && alt > 8 && vel < -6) {                     // burnt out too high
        deployChute(); tvcCenter(); state = CHUTE_DESCENT; Serial.println(F("ABORT: high burnout"));
      }
      break;
    case LANDED:
      if (ms - lastBeep > 2000) { lastBeep = ms; beep(3500, 500); }   // locator beeps
      serialService();
      break;
  }

  // liftoff confirmation: a bump on the pad never gets past here
  if ((state == BOOST || state == COAST) && !confirmed) {
    if (alt > CONFIRM_ALT) { confirmed = true; Serial.println(F("CLIMB CONFIRMED")); }
    else if (ms - tLaunch > CONFIRM_MS) {
      state = PAD; tvcCenter(); launchCount = 0; alt = vel = 0; Serial.println(F("false liftoff - back to PAD"));
    }
  }

  // touchdown: low, slow, still for 1.5 s
  if (state == CHUTE_DESCENT || state == LAND_BURN) {
    float a2 = ax * ax + ay * ay + az * az;
    bool still = ok && a2 > 0.64f && a2 < 1.44f && fabs(gx) + fabs(gy) + fabs(gz) < 20 && alt < 3 && fabs(vel) < 0.7f;
    stillCount = still ? stillCount + 1 : 0;
    if (stillCount > 300) {
      state = LANDED; tvcCenter();
      if (sdOK && logFile) { logLine(); logFile.close(); sdOK = false; }
      Serial.println(F("LANDED"));
    }
  }

  // logging: 10 Hz on the pad, 40 Hz in flight; no flush during burns (SD stalls)
  uint16_t period = state == PAD ? 100 : 25;
  if (state != LANDED && ms - lastLog >= period) {
    lastLog = ms; logLine();
    bool burning = state == BOOST || state == LAND_BURN;
    if (!burning && ms - lastFlush > 1000) { lastFlush = ms; if (sdOK && logFile) logFile.flush(); }
  }
}

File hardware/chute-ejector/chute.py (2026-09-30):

# Servo-latched spring parachute ejector for the RocketFC rocket (Apogee 3" / 74 mm body tube).
# Units mm. +Z = forward (nose). z = 0 is the underside of the bulkhead plate.
#
#  nose cone ─┐
#  parachute  │  chute bay (plain body tube above the piston)
#  PISTON  ───┤  pushed by one compression spring, pulled down by the STEM
#  spring     │
#  BULKHEAD ──┤  4x M3 radial screws into the tube (same scheme as the avionics bay)
#  LATCH CUP  │  rotates 90 deg on the servo: slot aligned = release, crossed = locked
#  SERVO      ┘  MG90S micro servo, hangs under the bulkhead
import cadquery as cq, math

TUBE_ID, TUBE_OD = 74.47, 76.20
R = 37.0                  # bulkhead OD 74.0
PIST_R = 36.7             # piston OD 73.4 (0.5 mm radial slide clearance)
PLATE_T = 5.0
BAND_H = 11.0             # screw band below the plate
INSERT_D, INSERT_L = 4.0, 6.0

# latch geometry
SLOT_L, SLOT_W = 17.0, 9.0        # keyhole slot in the bulkhead (x-long)
KEY_W, KEY_T = 16.0, 8.0          # T-head / stem bar width and thickness (bar fits inside the spring)
NECK_W = 7.0
CUP_SLOT = (17.5, 9.5)
CUP_CAV_D, CUP_OD = 20.6, 23.6
CUP_TOP, CUP_CAV, CUP_BOT = 3.0, 7.0, 5.0
HORN_SLOT_W, HORN_SLOT_D = 6.5, 4.0
T_HEAD_H = 6.0

# spring: 22 mm OD, 1.4-1.5 mm wire, 100 mm free, compressed to 35 mm (k ~0.4-0.55 N/mm -> 26-36 N preload)
SPRING_OD, SPRING_FREE, SPRING_COMP = 22.0, 100.0, 35.0
POCKET_D, POCKET_H = 23.0, 2.0
Z_SPRING0 = PLATE_T - POCKET_H              # spring seat
Z_PIST = Z_SPRING0 + SPRING_COMP            # piston plate underside when armed
PIST_TOP_T, SKIRT_H, SKIRT_T = 3.0, 15.0, 1.6

# servo (MG90S / SG90 class): spline top at z = SPLINE_Z
SPLINE_Z = -12.5
SERVO_BOT = SPLINE_Z - 29.0
EAR_TOP = SERVO_BOT + 18.4
SERVO_L, SERVO_W, SHAFT_OFF, EAR_PITCH = 22.8, 12.3, 5.5, 27.8
SHELF_T = 3.0

def cyl(x, y, r, z0, z1):
    return cq.Workplane('XY').workplane(offset=z0).center(x, y).circle(r).extrude(z1 - z0)
def box(x0, x1, y0, y1, z0, z1):
    return cq.Workplane('XY').box(x1 - x0, y1 - y0, z1 - z0, centered=False).translate((x0, y0, z0))
def ring(z0, z1, r0, r1):
    return cq.Workplane('XY').workplane(offset=z0).circle(r1).circle(r0).extrude(z1 - z0).rotate((0, 0, 0), (0, 0, 1), 7)
def arc_sector(r0, r1, a0, a1, z0, z1):
    ann = cq.Workplane('XY').workplane(offset=z0).circle(r1).circle(r0).extrude(z1 - z0)
    big = 3 * r1; m = math.radians((a0 + a1) / 2); h = math.radians((a1 - a0) / 2)
    pts = [(0, 0)] + [(big * math.cos(m + t), big * math.sin(m + t)) for t in (-h, -h / 2, 0, h / 2, h)]
    return ann.intersect(cq.Workplane('XY').workplane(offset=z0 - 1).polyline(pts).close().extrude(z1 - z0 + 2))
def radial_insert(angle, z):
    bore = cq.Workplane('YZ').circle(INSERT_D / 2).extrude(INSERT_L + 0.5).translate((R - INSERT_L, 0, z))
    tip = cq.Workplane('YZ').circle(1.4).extrude(1.5).translate((R - INSERT_L - 1.0, 0, z))
    return bore.union(tip).rotate((0, 0, 0), (0, 0, 1), angle)

# ================= 1. BULKHEAD + SERVO FRAME (one print, plate face down) =================
bh = cyl(0, 0, R, 0, PLATE_T).rotate((0, 0, 0), (0, 0, 1), 7)
bh = bh.union(ring(-BAND_H, 0, 32.0, R))
for a in (0, 90, 180, 270):
    bh = bh.union(arc_sector(29.0, R, a - 7, a + 7, -BAND_H, 0))
# servo frame: two side walls + ear shelf
FX0, FX1, WY0, WY1 = -24.0, 13.0, 14.0, 17.0
for s in (1, -1):
    bh = bh.union(box(FX0, FX1, min(s * WY0, s * WY1), max(s * WY0, s * WY1), EAR_TOP, 0))
bh = bh.union(box(FX0, FX1, -WY1, WY1, EAR_TOP, EAR_TOP + SHELF_T))
cx = -SHAFT_OFF
bh = bh.cut(box(cx - SERVO_L / 2 - 0.3, cx + SERVO_L / 2 + 0.3, -SERVO_W / 2 - 0.3, SERVO_W / 2 + 0.3, EAR_TOP - 1, EAR_TOP + SHELF_T + 1))
for ex in (cx - EAR_PITCH / 2, cx + EAR_PITCH / 2):
    bh = bh.cut(cyl(ex, 0, 0.9, EAR_TOP - 1, EAR_TOP + SHELF_T + 1))            # M2 self-tapping into the shelf
# plate features
bh = bh.cut(box(-SLOT_L / 2, SLOT_L / 2, -SLOT_W / 2, SLOT_W / 2, -1, PLATE_T + 1))   # keyhole slot
bh = bh.cut(cyl(0, 0, POCKET_D / 2, Z_SPRING0, PLATE_T + 1))                        # spring seat pocket
for x in (17.0, -17.0):
    bh = bh.cut(cyl(x, 0, 4.0, -1, PLATE_T + 1))                                  # air vents (piston must not suck a vacuum)
for sy in (1, -1):
    for x in (-5.0, 5.0):
        bh = bh.cut(cyl(x, sy * 25.0, 2.2, -1, PLATE_T + 1))                       # Kevlar shock-cord anchor holes
for a in (0, 90, 180, 270):
    bh = bh.cut(radial_insert(a, -BAND_H / 2))
bh = bh.cut(box(-1.0, 1.0, SLOT_W / 2 + 1.0, SLOT_W / 2 + 4.0, PLATE_T - 0.6, PLATE_T + 1))   # alignment tick next to slot

# ================= 2. LATCH CUP (on the servo horn) =================
z_ct = -0.2                       # cup top face when loaded (0.2 mm under the bulkhead; spring load presses it up)
cz0 = z_ct - (CUP_TOP + CUP_CAV + CUP_BOT)
cup = cyl(0, 0, CUP_OD / 2, cz0, z_ct)
cup = cup.cut(cyl(0, 0, CUP_CAV_D / 2, cz0 + CUP_BOT, z_ct - CUP_TOP))            # cavity for the T-head
cup = cup.cut(box(-CUP_SLOT[1] / 2, CUP_SLOT[1] / 2, -CUP_SLOT[0] / 2, CUP_SLOT[0] / 2, z_ct - CUP_TOP - 1, z_ct + 1))   # slot (drawn LOCKED: y-long)
cup = cup.cut(box(-CUP_OD, CUP_OD, -HORN_SLOT_W / 2, HORN_SLOT_W / 2, cz0 - 1, cz0 + HORN_SLOT_D))   # servo-horn arm slot
cup = cup.cut(cyl(0, 0, 4.2, cz0 - 1, cz0 + HORN_SLOT_D))                                            # horn hub
cup = cup.cut(box(-0.8, 0.8, CUP_OD / 2 - 1.2, CUP_OD / 2 + 1, z_ct - 1.5, z_ct + 1))                 # slot-direction notch

# ================= 3. STEM / LATCH KEY (printed flat, 8 mm thick) =================
zt_bot = z_ct - CUP_TOP - T_HEAD_H - 0.1           # T-head sits just under the cup top plate
z_neck0, z_neck1 = z_ct - CUP_TOP - 0.1, 0.0
z_cap0 = Z_PIST + PIST_TOP_T
hw, nw = KEY_W / 2, NECK_W / 2
prof = [(-hw, zt_bot), (hw, zt_bot), (hw, z_neck0), (nw, z_neck0), (nw, z_neck1), (hw, z_neck1), (hw, z_cap0),
        (11.0, z_cap0), (11.0, z_cap0 + 3.0), (-11.0, z_cap0 + 3.0), (-11.0, z_cap0), (-hw, z_cap0), (-hw, z_neck1),
        (-nw, z_neck1), (-nw, z_neck0), (-hw, z_neck0)]
stem = cq.Workplane('XZ').polyline(prof).close().extrude(KEY_T / 2, both=True)

# ================= 4. PISTON (printed top plate down) =================
pis = cyl(0, 0, PIST_R, Z_PIST - 1.5, Z_PIST + PIST_TOP_T)
pis = pis.union(ring(Z_PIST - 1.5 - SKIRT_H, Z_PIST - 1.5, PIST_R - SKIRT_T, PIST_R))
pis = pis.cut(cyl(0, 0, POCKET_D / 2, Z_PIST - 2.0, Z_PIST))                        # spring seat recess
pis = pis.cut(box(-KEY_W / 2 - 0.25, KEY_W / 2 + 0.25, -KEY_T / 2 - 0.25, KEY_T / 2 + 0.25, Z_PIST - 7, Z_PIST + PIST_TOP_T + 1))  # stem slot
for sy in (1, -1):
    pis = pis.cut(cyl(0, sy * 22.0, 2.6, Z_PIST - 3, Z_PIST + PIST_TOP_T + 1))    # chute bridle / shock cord
for a in range(45, 360, 90):
    pis = pis.cut(cyl(28 * math.cos(math.radians(a)), 28 * math.sin(math.radians(a)), 3.0, Z_PIST - 3, Z_PIST + PIST_TOP_T + 1))  # lightening
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
